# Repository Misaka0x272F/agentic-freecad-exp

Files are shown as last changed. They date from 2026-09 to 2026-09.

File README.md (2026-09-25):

# agentic-freecad-exp

Hands-on practice at **building real CAD with an agent driving FreeCAD** — and a
place to write down what that actually takes.

Not a reducer repository. Reducers happen to be the first project in it, because
they are unforgiving: a gear reducer has lots of parts, exact geometric
relationships, and mistakes that look fine in a render. That makes them a good
proving ground for the workflow.

The repository has two layers:

```
docs/practices/     knowledge that transfers to any agentic FreeCAD work
projects/           concrete builds, each self-contained and reproducible
```

---

## Practice notes

Design-agnostic, written from mistakes that got through. Read these before
building anything with an agent and FreeCAD.

| | |
|---|---|
| [Driving FreeCAD on another machine over MCP](docs/practices/01-remote-mcp-workflow.md) | architecture, setup, the IP-allowlist trap, where headless execution really runs, and why the remote environment must be re-probed every session |
| [FreeCAD API traps](docs/practices/02-freecad-api-traps.md) | 14 behaviours that fail **silently** — `Part::Feature.Shape` already carrying its placement, `Placement` rotating about the origin, booleans that return invalid solids, `distToShape` that cannot prove non-overlap, and the rest |
| [Verification methodology](docs/practices/03-verification-methodology.md) | how to prove generated geometry is correct rather than merely plausible: intersection volume, bounding-box pre-filtering, closed-form cross-checks, negative controls, orphan detection |
| [CAD assembly practice](docs/practices/04-cad-assembly-practice.md) | boolean ordering for castings, flange overhang and relief, bolt-head clearances, coplanar-face slivers, assembly-path constraints |

The short version, if you read nothing else:

1. **`Part::Feature.Shape` already has the Placement applied**, and assigning
   `.Shape` then `.Placement` bakes the rotation in and resets the Placement to
   identity. A local-frame feature cut through `obj.Shape` lands in the wrong
   place — silently, with `isValid()` still `True`.
2. **`distToShape == 0` cannot prove non-overlap.** Use intersection volume.
3. **Bounding boxes of boolean results are ~0.1 mm off** — enough to make an exact
   160.000 mm centre distance measure as 159.888 mm.
4. **`App.Placement` translates after rotating, about the origin.** To rotate about
   an arbitrary axis, `t = axis − R·axis`.
5. **Assert that features exist, and prove your checks can fail.** A verification
   step that has never failed is an untested verification step.

## Projects

| project | what it is | status |
|---|---|---|
| [reducers](projects/reducers/) | three cylindrical gear reducers (i = 3, 12, 8), script-generated, with an independent audit | two models committed and verified; the third is documented |

Each project is self-contained: its own `src/`, `models/`, `images/` and `docs/`.
Nothing in `projects/` is needed to understand `docs/practices/`, and vice versa.

<p align="center">
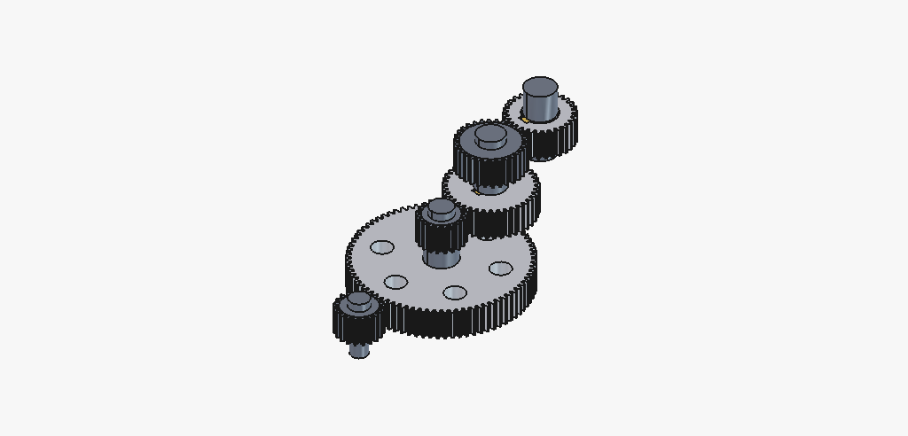
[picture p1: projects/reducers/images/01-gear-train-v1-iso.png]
three-stage gear train
  
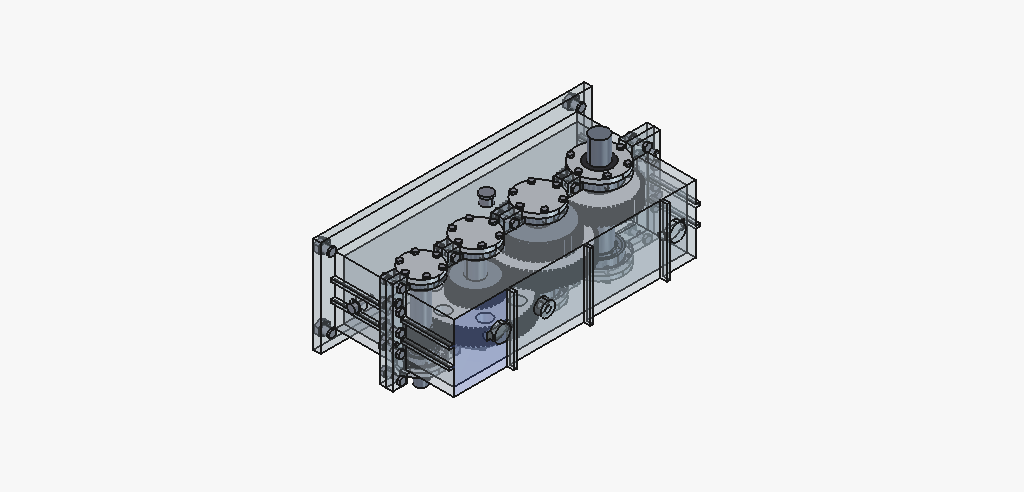
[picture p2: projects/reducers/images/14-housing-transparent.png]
assembly with translucent housing
  
</p>

```bash
git clone https://github.com/Misaka0x272F/agentic-freecad-exp
cd agentic-freecad-exp/projects/reducers

freecadcmd -P src -c "import build_two_stage as m; m.main()"   # build
freecadcmd -P src -c "import verify; verify.main('two')"       # audit
```

## Adding a project

`projects/reducers/` is the template. The conventions that make it work:

* **models are script-generated**, never hand-modelled — the script is the source
  of truth and the `.FCStd` is a build artifact;
* a project carries its own **design-conventions block** at the top of its shared
  library (`projects/reducers/src/common.py`); other sessions read that before
  contributing, rather than working from memory of a previous round;
* **build and verify are separate programs**, and the verifier re-opens the saved
  file rather than trusting the builder;
* anything learned that is *not* specific to the project goes into
  `docs/practices/`, not into the project's docs.

## Requirements

* FreeCAD with Python (`freecadcmd` on `PATH`) — developed against 1.0.0 and
  1.1.0
* the built-in `PartDesign.fcgear` module, shipped with FreeCAD; the FCGear addon
  is **not** needed
* `xvfb-run` only for offscreen rendering, and a lot of patience: software
  rendering of these models exceeded ten minutes per frame, which is why the
  committed images were captured from a native GUI instead

## Honesty notes

* These are **geometry** exercises. Nothing is stress-analysed; load capacity is
  not asserted anywhere.
* The practice notes describe one project's experience, not universal truths.
  Where two sessions observed *contradictory* behaviour from the same tool, the
  contradiction is recorded rather than resolved — see
  [the environment table](docs/practices/01-remote-mcp-workflow.md#probe-the-remote-environment-every-session--it-is-not-stable).
* `projects/reducers/models/original-build/` holds a first generation with
  defective hub keyways, kept as evidence rather than as reference geometry.

## License

MIT — see [LICENSE](LICENSE).

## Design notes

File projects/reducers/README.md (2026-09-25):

# Reducers

Three cylindrical gear reducers, built entirely by script and audited
part-by-part. This is the first project in the repository and the source of most
of the lessons now collected under [`docs/practices/`](../../docs/practices/).

| design | ratio | shafts | parts | material | model |
|---|---|---|---|---|---|
| [single-stage](docs/01-single-stage.md) | 3.000 | 2 | 14 | 7.74 L | `models/reducer_single_stage.FCStd` |
| [two-stage, expanded](docs/02-two-stage.md) | 12.000 | 3 | 21 | 16.34 L | `models/reducer_two_stage.FCStd` |
| [three-stage, expanded](docs/03-three-stage.md) | 8.000 | 4 | 41 | ≈ 22.6 L | *(not committed — see below)* |

Each design is a complete transmission plus its enclosure: involute gears with
genuine tooth profiles and root fillets, stepped shafts with GB/T 1096 keyways,
deep-groove ball bearings with balls, flanged end caps (through and blind), and a
split cast housing with bearing bosses, flanges, ribs and bolt holes.

| | single-stage | two-stage | three-stage |
|---|---|---|---|
| module | m = 4 | m₁ = 3, m₂ = 4 | m = 3 |
| teeth | 20 / 60 | 20 / 80 and 20 / 60 | 20 / 80, 38 / 76, 56 / 56 |
| centre distances | 160 | 150 and 160 | 150, 171, 168 |
| bearings | 6206 ×2, 6209 ×2 | 6206 ×2, 6209 ×2, 6214 ×2 | 6207 / 6208 / 6209 / 6211 |
| end caps | 2 through + 2 blind | 2 through + 4 blind | 2 through + 6 blind |

The two-stage and three-stage designs are **expanded** (展开式) layouts: the
intermediate shafts carry the wheel of one stage and the pinion of the next, so
the meshes sit at different axial stations. See
[docs/02](docs/02-two-stage.md) for why that shapes everything.

## Layout

```
src/
  common.py              reusable geometry + this project's design conventions
                         (read the docstring at the top first)
  housing.py             parameterised split-cast housing builder
  build_single_stage.py  design 1
  build_two_stage.py     design 2
  verify.py              independent audit; exits non-zero on failure
  render.py              offscreen PNG rendering (GUI-only; slow under Xvfb)
render.sh                wrapper that runs render.py
models/                  the two verified models, plus original-build/ holding the
                         first generation, whose hub keyways are defective
images/                  process renders: gear train, housing iterations,
                         bearings and end caps, assembly
docs/                    per-design records, the audit write-up, design notes
```

## Running it

```bash
cd projects/reducers

freecadcmd -P src -c "import build_single_stage as m; m.main()"
freecadcmd -P src -c "import build_two_stage as m; m.main()"

freecadcmd -P src -c "import verify; verify.main('single')"   # exits non-zero on failure
freecadcmd -P src -c "import verify; verify.main('two')"
```

`freecadcmd` treats a positional filename as a document to open, so the modules
have to be imported — see
[API traps §13](../../docs/practices/02-freecad-api-traps.md#13-freecadcmd-scriptpy-does-not-run-the-script).

## Verification results

Every committed model is audited by a **separate** program that re-opens the saved
file and re-derives geometry from scratch — it does not trust the builder.

| check | single-stage | two-stage |
|---|---|---|
| solids valid | 14 / 14 | 21 / 21 |
| centre distance, measured from cylindrical faces | 160.000000 mm | 150.000000 / 160.000000 mm |
| pairs with non-zero intersection volume | **0** of 91 | **0** of 210 |
| gear meshes touching without overlap | ✓ | ✓ both stages |
| keyway cut volume vs closed-form solution | 4 / 4 exact | 6 / 6 exact |
| tooth counts recovered by clustering tip vertices | 20 / 60 ✓ | 20 / 80 / 20 / 60 ✓ |

Three-stage build, as recorded by its session: 41 parts all valid, 820 pairs
pre-filtered to 201 candidates, **all zero**; connectivity analysis returns a
single component (no orphan parts); ratio 4.000 × 2.000 × 1.000 = 8.000.

Full output: [docs/04-verification.md](docs/04-verification.md).

## Design conventions

Full text at the top of `src/common.py`:

* millimetres and degrees;
* **shaft axes along +X, all axes in the plane z = 0** — the housing is split
  along that plane into `Housing_Base` (z < 0) and `Housing_Cover` (z > 0);
* gears are built in a local frame (**axis +Z, tooth centre on local +X**) and
  placed by `gear_placement()`;
* flat keys per GB/T 1096, selected by `key_for(shaft_diameter)`.

Anything built for this project must follow them. In particular, a model built
with a different convention cannot simply be dropped in — see
[assembly practice §9](../../docs/practices/04-cad-assembly-practice.md#9-coordinate-system-drift-between-sessions-is-a-real-risk).

## Why the three-stage model is not committed

Its 41 parts live only on the CAD host, and committing the binary would
contradict the point of the repository, which is that **models are produced by
scripts**. [docs/03-three-stage.md](docs/03-three-stage.md) records the design,
the process, the verification, and the fact that it was built in a *different*
coordinate convention (shafts along +Z, split at X = 0) — so it needs rotating
into this project's frame before it can be merged, not copying. That document is
in Chinese; the rest of this project's docs are in English.

## Honesty notes

* This is a **geometry** exercise. Nothing is stress-analysed: modules, tooth
  counts and widths were chosen for sensible proportions, not from a strength
  calculation. Load capacity is not asserted.
* Fasteners are modelled as **holes** in designs 1 and 2; the three-stage build
  modelled them as solids and hit the interference problems recorded in
  [assembly practice](../../docs/practices/04-cad-assembly-practice.md) as a
  result.
* Bearings are simplified: rings and balls, no cage, no fillets, catalogue sizes.
* `models/original-build/` holds the first-generation files, which have defective
  hub keyways and spurious rim slots — they are kept as evidence, not as
  reference geometry. The committed models are rebuilt with the fix and fully
  audited.

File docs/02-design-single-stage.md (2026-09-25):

# Design 1 — single-stage cylindrical gear reducer

`src/build_single_stage.py`

## Specification

| | |
|---|---|
| module | m = 4 mm |
| pressure angle | α = 20° |
| teeth | z₁ = 20 (pinion) / z₂ = 60 (wheel) |
| ratio | i = 3.000 |
| pitch diameters | d₁ = 80 mm, d₂ = 240 mm |
| tip / root diameters | 88 / 70 mm and 248 / 230 mm |
| centre distance | a = 160 mm |
| face widths | 50 mm (pinion), 45 mm (wheel) |
| bearings | 6206 (30×62×16) ×2, 6209 (45×85×19) ×2 |

Shaft axes lie in the plane `z = 0`, 160 mm apart along Y. Stage layout is
deliberately the simplest possible: one gear pair, no axial offset.

```
        y
        ▲
  160 ──┼──────────────●  shaft II (output, extends right)
        │             ╱ ╲
        │            │   │  wheel z=60
        │             ╲ ╱
        │              │
        │              ●   mesh, a = 160
        │             ╱ ╲
    0 ──┼────────────●   │  pinion z=20
        │             ╲ ╱
        └──────────────▶ x
                        shaft I (input, extends left)
```

## Shafts

Both shafts are stepped, with the shoulder between the gear seat and the bearing
seat acting as the axial locating feature for both the gear hub and the bearing
inner ring.

| shaft | segments (Ø × x-range) | length | extension |
|---|---|---|---|
| I (input) | Ø25 `[-120,-78]`, Ø30 `[-78,-40]`, Ø36 `[-40,40]`, Ø30 `[40,55]` | 175 | left |
| II (output) | Ø45 `[-55,-37]`, Ø55 `[-37,37]`, Ø45 `[37,56]`, Ø40 `[56,115]` | 170 | right |

The input shaft carries the pinion on its Ø36 seat; the output shaft carries the
wheel on its Ø55 seat. The extension ends are Ø25 and Ø40, ready for a coupling.

## Keyways

Four keyways, GB/T 1096 flat keys, chosen from the shaft diameter by
`key_for()`:

| location | shaft Ø | key b×h | groove t₁ | length | cut volume vs analytic |
|---|---|---|---|---|---|
| input, gear seat | Ø36 | 10×8 | 5.0 | 50 mm | 2382.9 / 2382.9 mm³ |
| input, coupling | Ø25 | 8×7 | 4.0 | 36 mm | 1089.6 / 1089.6 mm³ |
| output, gear seat | Ø55 | 16×10 | 6.0 | 45 mm | 4037.1 / 4037.1 mm³ |
| output, coupling | Ø40 | 12×8 | 5.0 | 37 mm | 2084.9 / 2084.9 mm³ |

Both coupling keyways are **open at the shaft end** so a coupling hub can slide
on. All keyways on one shaft share an angular direction, as they would if milled
in a single setup; that direction is inherited from the gear's mesh phase.

Matching hub grooves (`t₂`) are cut into the gear bores in the gears' own local
frames — see `make_gear_solid(..., key=...)`.

## Bearings and end caps

Bearings sit flush with the inner end of the housing bore, so the outer face of
each bearing lands exactly on the plane the cap spigot reaches. That is what
makes the cap clamp the bearing outer ring.

| | input | output |
|---|---|---|
| bearing | 6206, 30×62×16 | 6209, 45×85×19 |
| bore in housing | Ø62 | Ø85 |
| cap bolt circle D₀ | 82 | 105 |
| cap flange D₂ | 102 | 125 |

Cap sizes follow the standard flanged pattern with M8 screws:

```
D0 = D + 2.5·d3 = D + 20      bolt circle
D2 = D0 + 2.5·d3 = D + 40     flange outside diameter
e  = 1.2·d3 = 9.6 → 10 mm     flange thickness
e1 = 0.8·e = 8 mm             spigot length
```

Two through caps (input-left, output-right — where the shafts leave the housing),
two blind caps.

## Housing

Split along the plane through both shaft axes (`z = 0`) into `Housing_Base`
(z < 0) and `Housing_Cover` (z > 0).

| dimension | value |
|---|---|
| cavity lobes | (y=0, r=56), (y=160, r=136) — gear tip radius + 12 mm |
| wall thickness | 8 mm |
| cavity axial half-length | 37 mm |
| end wall / boss face | ±47 / ±64 mm |
| oil-sump floor | z = −130 mm (6.1 mm below the wheel's lowest tooth) |
| casting bottom | z = −140 mm |
| split flange | 12 mm per half, 24 mm radial overhang |
| bore length | 27 mm (bearing + 8 mm spigot) |

The lower half is a rectangular box rather than a continuing circle: real bases
are boxy, and it gives a genuinely flat bottom. The cover is the two-lobe dome.
The split flange is a rim around the outline plus an "ear" around each bearing
boss, so the bearing-adjacent bolts have material to sit in.

Bolting: 4 × M8 per end cap, 12 split-flange bolts, 4 foundation bolts.

## Result

14 parts, 7744.2 cm³ of material (≈ 56 kg as cast iron), all solids valid, every
pairwise intersection volume zero, centre distance exactly 160.000000 mm, and
both meshes touching without overlap.

See [verification](05-verification.md) for the full audit output.

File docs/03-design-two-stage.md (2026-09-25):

# Design 2 — expanded two-stage cylindrical gear reducer

`src/build_two_stage.py`

## Specification

| | stage 1 (high speed) | stage 2 (low speed) |
|---|---|---|
| module | m₁ = 3 mm | m₂ = 4 mm |
| teeth | z₁ = 20 / z₂ = 80 | z₃ = 20 / z₄ = 60 |
| ratio | i₁ = 4.000 | i₂ = 3.000 |
| pitch diameters | 60 / 240 mm | 80 / 240 mm |
| tip diameters | 66 / 246 mm | 88 / 248 mm |
| centre distance | a₁ = 150 mm | a₂ = 160 mm |
| face widths | 55 / 50 mm | 65 / 60 mm |

**Total ratio i = i₁ · i₂ = 12.000.**

| shaft | y | role | extension |
|---|---|---|---|
| I | 0 | high speed | extends left |
| II | 150 | intermediate | fully enclosed |
| III | 310 | low speed | extends right |

| | shaft I | shaft II | shaft III |
|---|---|---|---|
| gear carried | stage-1 pinion | stage-1 wheel **and** stage-2 pinion | stage-2 wheel |
| gear bore | Ø36 | Ø50 / Ø50 | Ø80 |
| bearing | 6206 (30×62×16) | 6209 (45×85×19) | 6214 (70×125×24) |
| housing bore | Ø62 | Ø85 | Ø125 |
| cap bolt circle / flange | 82 / 102 | 105 / 125 | 145 / 165 |

## Why the two meshes sit at different axial stations

This is the defining feature of the **expanded (展开式)** layout: the intermediate
shaft carries the stage-1 wheel *and* the stage-2 pinion. Both gears are on the
same axis, so the two meshes cannot share an axial band.

```
                    stage 2 mesh (x = +45)          stage 1 mesh (x = -45)
                                                       
  y=310  ●━━━━━━━━━━━━━━━━━━━━━━━━━━━━●  G4 wheel z=60 (green)
                                        ╲
                                         ╲  a2 = 160
                                        ╱
  y=150  ●━━━━● G3 pinion z=20 (red)   ●━━━━● G2 wheel z=80 (yellow)
                ╲                     ╱
                 ╲  a1 = 150         ╱
                ╱                   
  y=0    ●━━━━● G1 pinion z=20 (orange)
         └──────────────────────────────▶ x
        x = -45                x = +45
```

Consequences that shaped the geometry:

* the gear bands must not overlap axially — stage-1 gears occupy
  `x ∈ [-72.5, -17.5]`, stage-2 gears `x ∈ [12.5, 77.5]`;
* the housing cavity is correspondingly long: `x ∈ [−82, +82]`;
* the intermediate shaft carries two gears with **different** mesh phases, so its
  two keyways point in different directions.

Gear 2 (z₂ = 80) and gear 3 (z₃ = 20) are radially nested — the big wheel and the
small pinion are concentric on shaft II — which is only possible because they are
axially separated.

## Axial layout

| | value |
|---|---|
| cavity half-length | 82 mm |
| end wall / boss face | ±92 / ±114 mm |
| bearing outer face | ±106 mm (boss face − 8 mm spigot) |
| cap flange | ±[114, 124] mm |

Shaft diameter steps are placed **outside** the cap spans `|x| ∈ [106, 124]`, so
that a through cap's central bore — sized on the smaller diameter — cannot
collide with a larger section. This is a direct consequence of a bug found and
fixed during the build; see
[lessons-learned D4](06-lessons-learned.md#d4-clearances-the-housing-must-respect).

## Shafts

| shaft | segments (Ø × x-range) | length |
|---|---|---|
| I | Ø25 `[-165,-126]`, Ø30 `[-126,-85]`, Ø36 `[-85,-5]`, Ø30 `[-5,105]` | 270 |
| II | Ø45 `[-105,-72]`, Ø50 `[-72,-18]`, Ø45 `[-18,10.5]`, Ø50 `[10.5,79.5]`, Ø45 `[79.5,105]` | 210 |
| III | Ø70 `[-105,9]`, Ø80 `[9,81]`, Ø70 `[81,126]`, Ø65 `[126,165]` | 270 |

The intermediate shaft has **no** extension: both of its ends are enclosed, so it
gets two blind caps. The Ø45 spacer between its two Ø50 gear seats provides the
shoulders that locate the wheel and the pinion.

## Keyways

Six keyways — two per shaft (gear seat + coupling where the shaft extends).

| location | shaft Ø | key b×h | t₁ | length | cut / analytic |
|---|---|---|---|---|---|
| I gear seat | Ø36 | 10×8 | 5.0 | 55 mm | 2621.2 / 2621.2 mm³ |
| I coupling | Ø25 | 8×7 | 4.0 | 36 mm | 1059.3 / 1059.3 mm³ |
| II wheel seat | Ø50 | 14×9 | 5.5 | 50 mm | 3618.6 / 3618.6 mm³ |
| II pinion seat | Ø50 | 14×9 | 5.5 | 65 mm | 4704.1 / 4704.1 mm³ |
| III wheel seat | Ø80 | 22×14 | 9.0 | 60 mm | 11206.7 / 11206.7 mm³ |
| III coupling | Ø65 | 18×11 | 7.0 | 37 mm | 4263.6 / 4263.6 mm³ |

Note that shafts I and III each extend from one end, so the coupling keyway is
open at the free end while the gear-seat keyway is closed — the analytic volume
is computed on the *effective* length, i.e. the part of the cutter that is
actually inside the material.

## Housing

| dimension | value |
|---|---|
| cavity lobes | (y=0, r=45), (y=150, r=135), (y=310, r=136) |
| wall thickness | 8 mm |
| cavity half-length | 82 mm |
| oil-sump floor | z = −130 mm (6.0 mm below the stage-2 wheel's lowest tooth) |
| casting bottom | z = −140 mm |
| split flange | 12 mm per half, 24 mm overhang |
| base plate | 200 × 531 × 19 mm, 4 × M18 foundation bolts |

Bolting: 4 × M8 per end cap (6 caps), split-flange bolts at both Y extremes and
in pairs beside each bearing boss, 4 foundation bolts.

## Result

21 parts, 16336.3 cm³ (≈ 118 kg as cast iron), all solids valid, all 210 pairwise
intersection volumes zero, both centre distances exact to 10⁻⁶ mm, both meshes
touching without overlap.

See [verification](05-verification.md) for the full audit output.

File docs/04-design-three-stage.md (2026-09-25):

# 三级展开式圆柱齿轮减速器 i = 4 / 2 / 1

**状态**：模型已完成并通过全部校验，但**尚未入库**——本体只在远程 FreeCAD 上
（`<cad-host>:/Reducer_Full_i4_2_1.FCStd`），本仓库的 `models/`
和 `src/` 里还没有对应产物。原因与建议见第 5、6 节。

**坐标约定**：本模型用**轴沿 +Z、箱体沿 X=0 剖分**，与仓库约定（轴沿 +X、
沿 z=0 剖分）不同。这是本次最大的遗留问题，见 5.1。

---

## 1. 任务

分四轮：

1. 新建 FreeCAD 项目，绘制传动比 4/2/1 的直齿圆柱齿轮减速器 → 需求确认为
   **三级减速，各级 i₁=4、i₂=2、i₃=1，总 8:1**；范围为**仅传动系统**
2. 追加**箱体、轴承、端盖** → 确认为**剖分式箱体**、**深沟球轴承**、
   **含标准附件**，并**允许重配齿数**（传动比严格不变）
3. 箱体与箱盖改为**透明**
4. 清理**多余/游离结构**

---

## 2. 最终设计参数

### 2.1 齿轮

m = 3，α = 20°，hₐ\* = 1.0，c\* = 0.25，齿宽 b = 40。

| 齿轮 | z | 分度圆 | 齿顶圆 | 齿根圆 | 所在轴 | 轴向区段 (Z) |
|---|---|---|---|---|---|---|
| z1 | 20 | Ø60 | Ø66 | Ø52.5 | I | 0 – 40 |
| z2 | 80 | Ø240 | Ø246 | Ø232.5 | II | 0 – 40 |
| z3 | 38 | Ø114 | Ø120 | Ø106.5 | II | 45 – 85 |
| z4 | 76 | Ø228 | Ø234 | Ø220.5 | III | 45 – 85 |
| z5 | 56 | Ø168 | Ø174 | Ø160.5 | III | 90 – 130 |
| z6 | 56 | Ø168 | Ø174 | Ø160.5 | IV | 90 – 130 |

齿数比：80/20 = **4.000**，76/38 = **2.000**，56/56 = **1.000**，总 **8.000**。

轴心（Y）：I = 0，II = 150，III = 321，IV = 489。
中心距：a₁₂ = 150，a₂₃ = 171，a₃₄ = 168。

**齿数是被重配过的**（第一轮是 20/80/20/40/30/30）。原因：展开式布局要求第一级
大齿轮的齿顶圆让开下一根轴，即

```
da₂/2 + d_III(轴颈)/2 + Δ  <  a₂
```

第一轮 20/80/20/40 时 da₂/2 = 123 而 a₂ = 90，齿顶**扫过 III 轴中心线 33 mm**，
三级齿轮被迫沿轴向错开 180 mm，III 轴就无法伸到第一级的轴向区段去装轴承——
箱体做不成标准两壁结构。

重配后：`123 + 22.5 = 145.5 < 171`（余量 25.5），
`117 + 27.5 = 144.5 < 168`（余量 23.5），三级齿轮得以收进同一轴向区段
（三个 40 mm 齿宽带，带间 5 mm）。

### 2.2 轮齿相位

`PartDesign.fcgear` 把齿中心放在局部 0°，齿槽中心在 `180/z`。对每一对啮合
（小轮在低 Y 侧）：

```
φ_小轮 = 90°                        （齿中心指向 +Y）
φ_大轮 = 270° − 180°/z_大轮          （齿槽中心指回 −Y）
```

实际取值：z1 90°，z2 267.750°，z3 90°，z4 267.6316°，z5 90°，z6 266.7857°。

### 2.3 轴系

四根轴都是阶梯轴，带轴承轴颈、定位轴肩、装拆台阶（轴承从轴端滑入并靠轴肩
定位）。z1 / z3 / z5 为**整体齿轮轴**。

| 轴 | 轴承 | 轴颈 | 齿轮轴颈 | 轴伸 |
|---|---|---|---|---|
| I（输入） | 6207 | Ø35 | 齿体 Ø52.4 | Ø30，Z −100…−40 |
| II | 6208 | Ø40 | z2 座 Ø45 / 齿体 Ø106.4 | 无 |
| III | 6209 | Ø45 | z4 座 Ø50 / 齿体 Ø160.4 | 无 |
| IV（输出） | 6211 | Ø55 | z6 座 Ø60 | Ø48，Z 174…250 |

平键按 GB/T 1096，键长 36：

| 齿轮 | 轴径 | 键 | t₁ | t₂ |
|---|---|---|---|---|
| z2 | Ø45 | 14×9 | 5.5 | 3.8 |
| z4 | Ø50 | 16×10 | 6.0 | 4.3 |
| z6 | Ø60 | 18×11 | 7.0 | 4.4 |

### 2.4 箱体

剖分面取 **X = 0**（四根轴心恰好都在该面上），箱座 X<0、箱盖 X>0。

| 项 | 值 |
|---|---|
| 壁厚 | 12 |
| 内腔 | X (−163, 138)，Y (−48, 591)，Z (−15, 145) |
| 外形 | X (−175, 150)，Y (−60, 603)，Z (−27, 157) |
| 剖分凸缘 | 厚 18，四周外伸 35 |
| 轴承座凸台 | Ø100 / 110 / 115 / 130，外伸 13 / 14 / 15 / 17 |
| 轴承孔深 | 轴承宽 + 8（留 6 mm 止口） |
| 地脚凸缘 | X (−195, −175)，4×Ø24 |
| 油池 | 液面 X = −103，最大齿轮 z2 浸油 20 mm（≈1/6 半径） |
| 加强肋 | 箱盖顶面 3 道（Y = 90 / 300 / 510）；两端壁各 2 道（Z = 45 / 95） |

### 2.5 轴承与端盖

8 套深沟球轴承，每套含内圈、外圈、9 颗滚球，做成 `Part.makeCompound` 复合体。
8 个端盖：**2 个透盖**（输入轴 Ø30 油封 30×47×7、输出轴 Ø48 油封 48×72×8）
+ **6 个闷盖**；每个端盖 6×M8，止口 6 mm。
端盖螺栓在凸台里配 Ø6.8×16 螺纹底孔。

### 2.6 标准附件

剖分面螺栓 M12×16（头 + 螺母）· 定位圆锥销 Ø10×2 · 起盖螺钉 M10×2 ·
放油螺塞 M20 · 油标尺 · 通气器 · 地脚螺栓 M20×4 · 吊环凸台 ×2

---

## 3. 过程

### 3.1 第一轮：仅传动系统

先探测远程 API：`Gui` 模块不可用、`App.Vector` 不存在，但
`PartDesign.fcgear` 可通过 `fcgear.fcgear.FCWireBuilder` 调用。

动手前先用**布尔干涉量**验证啮合相位公式：正确相位下 `common()` 体积 = 0，
把从动轮再转过半个齿距则得到 ~1900 mm³ 干涉——先确认这个判据有区分度，再拿它
当尺子用（见 lessons-learned 4.4）。

然后建 6 齿轮 + 4 轴 + 3 键，45 对零件干涉全为 0。

### 3.2 第二轮：完整减速器

**先发现齿数不可用**（见 2.1），重配齿数 → 重建传动系 → 建箱座/箱盖 →
建轴承/端盖 → 补附件。

这一轮踩的坑最多，按被发现顺序：

| # | 现象 | 根因 | 对策 |
|---|---|---|---|
| 1 | 箱体与传动系**全部**干涉 | 剖分凸缘是实体板，我**先切内腔后并凸缘**，凸缘把内腔填实了 | 改为先并完所有凸缘/凸台，**最后**切内腔 |
| 2 | 轴伸与箱体干涉 | 剖分凸缘沿 ±Z 外伸 35 挡住了轴伸 | 在每个轴承座处挖避让孔（半径 = 凸台半径 + 8，Z 只到凸台端面） |
| 3 | 凸缘螺栓与箱座干涉 26905 mm³ | 凸缘在 Z 向不外伸，螺母埋在箱座实体里 | 给 Z 向外伸（配合 #2 的避让孔） |
| 4 | 轴承内圈与轴干涉 | 内圈内孔半径写成了 `d/2 − 1`（比轴颈小 1 mm） | 改为 `d/2 + 0.05`（0.1 mm 间隙） |
| 5 | 闷盖与端盖螺栓干涉 3619 mm³ | `end_cap()` 里的螺栓孔布尔**静默未生效** | 单独再切一次螺栓孔；螺栓分 Ø8 穿盖段 + Ø6.6 入螺孔段 |
| 6 | 凸缘螺栓头与端壁加强肋干涉 | 六角头外接圆 0.577·af 与肋相碰 | 肋从 Z=30/110 挪到 Z=45/95 |
| 7 | 起盖螺钉与凸缘螺栓干涉 | 两者间距 14.8 < 所需 19.6 | 挪到 Y 向凸缘中部（Z=45 / 145） |
| 8 | 螺栓头/螺母端面与凸缘面残留 111 mm³ 干涉 | 精确共面产生数值薄片 | 端面内缩 0.2 mm |

期间还出现过一次**误判为卡死**：最后那条全量校验（41 件 820 对）跑了 2 分钟
多，用户以为 FreeCAD 挂了。`get_rpc_status` 报 `state: busy` 才确认是在跑。
之后改成包围盒预筛，820 → 201 对，秒级完成（见 lessons-learned 4.3、5.3）。

### 3.3 第三轮：透明

箱座/箱盖 `ViewObject.Transparency = 75`，便于看内部传动系。

### 3.4 第四轮：清理多余结构

用户指出通气器「游离在主体外」。用**连通性分析**（包围盒重叠 + 并查集）定量
确认：`Breather` 自成连通分量，**离最近零件 50.3 mm**。

根因是**建模辅助函数的轴向 bug**：我用沿 +Z 构建的 `cyl()` 去造通气器（它应沿
+X），而 `.translated()` 只平移、不换轴。同一轮还查出放油螺塞的六角头也拐错了
方向——`hex_prism(..., axis='Y')` 只实现了 `'X'` 分支，非法取值被**静默忽略**。

两处都改为显式指定轴线后重建，并顺手把螺塞头部与凸台端面的 3 mm 缝隙贴平
（基准面取错：把箱壁外表面 Y=603 当成了凸台端面 Y=619）。

---

## 4. 校验

| 项目 | 结果 |
|---|---|
| 零件数 | 41，全部 `isValid() == True` |
| 两两干涉 | 包围盒预筛 820 → 201 对，**干涉全为 0** |
| 连通分量 | **1**（无游离件） |
| 传动比 | 4.000 × 2.000 × 1.000 = **8.000** |
| 展开式让空 | 145.5 < 171；144.5 < 168 |
| 啮合相位 | 正确相位干涉 0；错开半齿距 ~1900 mm³（判据有区分度） |
| 整机外形 | Y 743 × Z 365；X ≈ 403（−207.5 … 196，X 上限来自通气器顶盖） |

**存档凭据**（远程）
- `Reducer_Full_i4_2_1.FCStd` — 完整减速器，41 件，811.6 KB
- `Reducer_i4_2_1.FCStd` — 仅传动系统的第一轮版本

> 最终体积/质量的精确复测未能完成：写本文时远程 FreeCAD 的 GUI 调度被占
> （`get_rpc_status` 报 healthy，但 `execute_code` 排队 90 s 都进不去 —— 典型的
> 远程端开着模态对话框）。按 41 件的材料体积约 22.6 L 估，钢制约 177 kg。

---

## 5. 与仓库约定的偏差

### 5.1 坐标系（重要）

| | 本仓库约定 | 本次模型 |
|---|---|---|
| 轴方向 | **+X** | **+Z** |
| 轴心所在平面 | z = 0 | y = 0 |
| 剖分面 | z = 0 | **X = 0** |
| 齿轮局部系 | 轴 +Z、齿中心局部 +X | 同（一致） |
| 箱座/箱盖 | `Housing_Base` (z<0) / `Housing_Cover` (z>0) | `HousingBase` (X<0) / `HousingCover` (X>0) |

两套系的 `Placement`、相位公式、端盖/轴承的轴向定义、视图方向全都不同。三级模型
若要并入本仓库，需要整体旋转到 +X / z=0 系，**不能**直接混用。

### 5.2 未复用仓库的工具

本次没有 import `src/common.py`，而是在远程手搓脚本（常量写成一个
`reducer_params.py` 模块 import 以避免漂移）。代价是重复实现且偏离约定；
仓库里已有的 `mesh_phases()`、`key_for()`、`make_bearing()`、`make_end_cap()`、
`cap_dimensions()` 本都可以直接用。

### 5.3 命名

仓库用 `Housing_Base` / `Housing_Cover` / `Gear_*` / `Shaft_*`（带下划线前缀），
本次用了 `HousingBase` / `HousingCover`。

---

## 6. 后续建议（按价值排序）

1. **按仓库约定重写 `src/build_three_stage.py`**，用 `common.py` 的
   `mesh_phases` / `make_shaft` / `make_bearing` / `make_end_cap` / `key_for`，
   转到 +X / z=0 系，输出 `models/reducer_three_stage.FCStd`。
   这比把远程的二进制拷进来有价值得多——仓库的约定就是**模型由脚本生成**。
   `src/housing.py` 的 `build_housing()` 目前按「每根轴一个圆瓣」的轮廓建箱体，
   三级（4 根轴、轴心 0/150/321/489 共线）需要确认它能直接吃下这个 spec。
2. **把三级加入 `src/verify.py` 的 `MODELS`**，复用它的独立复算：齿数/齿顶半径/
   齿宽、轮毂键槽角度、轴同轴度、中心距、两两干涉。
3. **补 `src/render.py`**（`common.py` 顶部已声明颜色/截图应集中在此）。
4. 补 `README.md`，并 `git init` 纳入版本管理。

---

## 7. 图集

`images/` 按过程顺序：

| 文件 | 内容 |
|---|---|
| `01-gear-train-v1-iso.png` | 第一轮传动系（齿数 20/80/20/40/30/30），等轴测 |
| `02-gear-train-v1-top.png` | 第一轮俯视：四轴共线布局 |
| `03-gear-train-v1-front.png` | 第一轮正视：三级齿轮轴向错开 180 mm |
| `04-gear-train-v2-iso.png` | 重配齿数后的传动系 |
| `05-housing-base.png` | 箱座（内含传动系） |
| `06-housing-cover.png` | 箱盖 |
| `07-housing-cavity-fixed.png` | 修正布尔顺序（先并后挖）之后的箱体 |
| `08-housing-bore-audit-top.png` | 轴承座孔与凸台俯视核对 |
| `09-bearings-and-end-caps.png` | 轴承与端盖装好 |
| `10-accessories.png` | 补上标准附件 |
| `11-flange-bolts-rebuilt.png` | 凸缘螺栓按新方位重建 |
| `12-housing-final-top.png` | 箱体最终俯视：凸缘四周外伸 + 16 颗螺栓 |
| `13-assembly-coloured.png` | 全装配上色 |
| `14-housing-transparent.png` | 箱体透明，可见内部传动系 |
| `15-assembly-left.png` | 左视：轴承座、端盖、端壁肋 |

---

## 8. 经验教训

完整的坑清单在 [`docs/06-lessons-learned.md`](06-lessons-learned.md)，其中带 `[3rd]`
标记的条目来自本次会话。最值得记住的三条：

1. **先并后挖**：箱体类零件的凸缘是实体板，必须并完所有凸台再切内腔。
2. **大批量干涉校验先做包围盒预筛**：820 对要 2 分钟且看起来像死机，
   预筛后秒级完成、结论不变。
3. **辅助函数要把「轴」写进名字或做参数校验**：沿 Z 的 `cyl()` 被
   `.translated()` 调用时不会报错，只会静默产出错轴零件。

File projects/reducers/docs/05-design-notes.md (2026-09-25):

# Design notes

Notes specific to cylindrical gear reducers, as opposed to the general FreeCAD
practice collected under [`docs/practices/`](../../../docs/practices/).

---

## 1. Integral gear shaft (齿轮轴) criterion

A pinion is made integral with its shaft when its root circle is close to the
shaft diameter; the usual rule of thumb is `d_f / d_shaft < 1.5`.

| gear | d_f | shaft | ratio | verdict |
|---|---|---|---|---|
| stage-1 pinion (m=3, z=20) | 52.5 | Ø36 | 1.46 | marginal — integral is reasonable |
| stage-2 pinion (m=4, z=20) | 70 | Ø50 | 1.40 | marginal — integral is reasonable |
| stage-1 wheel (z=80) | 232.5 | Ø50 | 4.65 | separate gear |
| stage-2 wheel (z=60) | 230 | Ø80 | 2.88 | separate gear |

A 240 mm wheel on an output shaft is emphatically **not** a gear-shaft candidate:
an integral Ø230 blank on a Ø80 shaft wastes material, cannot be replaced when
worn, and gains nothing.

## 2. Expanded (展开式) layout

The intermediate shaft carries both the wheel of one stage and the pinion of the
next, so the two meshes must sit at **different axial stations**. Both gears of a
mesh share an axial band; the bands are offset. The shaft axes are collinear in
plan view.

Consequences that shape the whole design:

* gear bands must not overlap axially;
* the housing cavity becomes correspondingly long;
* an intermediate shaft carrying two gears has **two keyways pointing in
  different directions**, since each follows its own gear's mesh phase.

## 3. Meshing phase for a pair whose line of centres is along +Y

With the gear axis laid along +X and the gear spun by `ψ` about that axis, a
feature at local angle `θ` points at world direction `(0, sin(θ+ψ), −cos(θ+ψ))`.
For a standard (zero-backlash) mesh:

* pinion: tooth towards the wheel → `ψ_p = 90° − 0°`
* wheel: space towards the pinion → `ψ_w = 270° − 180°/z_w`

The wheel's `180°/z_w` term is the half-tooth-pitch offset between a tooth centre
and a space centre in the generator's convention. Measured result: the pair then
touches at exactly one point (`distToShape == 0.0000 mm`) with **zero**
intersection volume.

### Establishing the generator's convention

`PartDesign.fcgear` centres a **tooth on the local +X axis**, with a space at half
pitch. That was measured, not assumed, and the first measurement was wrong:

the tip of an involute tooth as generated here is effectively a **point** — the
plateau where `r == r_tip` is 0.048° wide, while the root plateau is 2.57° wide.
Scanning for "the angle that maximises the radius" therefore returns whichever
edge of the plateau the scan reaches first, and the phase came out ~1.8° off.

Two reliable methods:

* evaluate the radius at candidate angles directly
  (`r(0°) = 44.002`, `r(9°) = 35.000`, …);
* find the flank crossings of the pitch circle, where `r == m·z/2`.

Both gave the same answer.

## 4. Clearances

* cavity wall radius = gear tip radius + 10…15 mm (12 used here);
* the **oil-sump floor must clear the lowest tooth of the whole train** — see
  [assembly practice §8](../../../docs/practices/04-cad-assembly-practice.md);
* a bottom wall of ≥ 8–10 mm below the sump floor;
* the expanded layout's axial length is driven by the sum of the two gear bands
  plus the gap between them.

## 5. Layout choices made in these designs

* shafts axes all in the plane `z = 0`, so the housing splits along that plane;
* each shaft extends from **one** end only, which is what makes the through/blind
  cap split meaningful (an enclosed intermediate shaft gets two blind caps);
* gear hubs are keyed, not shrunk or splined, so every gear seat has a keyway and
  every hub has a matching groove at the same angular position.

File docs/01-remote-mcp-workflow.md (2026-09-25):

# The remote-MCP workflow

## Goal

Drive **FreeCAD running on a different machine** from an agent, over the
[Model Context Protocol](https://modelcontextprotocol.io), and produce real
engineering geometry rather than a toy demo.

```
┌─ agent machine ────────────────────────────┐   ┌─ CAD machine ────────────────┐
│                                            │   │                              │
│  CodeBuddy  ──stdio──▶  freecad-mcp        │   │   FreeCAD (GUI)              │
│  (LLM agent)            (MCP server,       │   │     └─ FreeCADMCP addon      │
│                          `uvx freecad-mcp  │──XML-RPC──▶  XML-RPC server     │
│                           --host HOST`)    │   │              :9875           │
│                                            │   │     (IP-allowlisted,         │
│                                            │   │      GUI-thread dispatch)    │
└────────────────────────────────────────────┘   └──────────────────────────────┘
```

Two components are involved and they are easy to confuse:

| component | runs on | role |
|---|---|---|
| `freecad-mcp` (Python package) | the **agent** machine | MCP server; translates MCP tool calls into XML-RPC |
| `FreeCADMCP` addon | the **CAD** machine, inside FreeCAD | XML-RPC server; executes code on FreeCAD's GUI thread |

## Setup

### 1. On the CAD machine

Copy `addon/FreeCADMCP` from the freecad-mcp repository into FreeCAD's addon
directory, restart FreeCAD, switch to the **MCP Addon** workbench, and in the
**FreeCAD MCP** toolbar:

1. tick **Remote Connections** (the server will bind `0.0.0.0` on next restart);
2. click **Configure Allowed IPs** and add the agent machine's address — a single
   IP is safer than a subnet. The default is `127.0.0.1` only;
3. restart the RPC server;
4. optionally tick **Auto-Start Server** so it comes up with FreeCAD.

### 2. On the agent machine

```bash
# CodeBuddy
codebuddy mcp add --scope user freecad -- uvx freecad-mcp --host <cad-host>
codebuddy mcp list          # expect: freecad ... ✓ Connected
```

`uvx` fetches and runs the published package; no clone is needed. For other MCP
clients the equivalent entry is:

```json
{
  "mcpServers": {
    "freecad": { "command": "uvx", "args": ["freecad-mcp", "--host", "<cad-host>"] }
  }
}
```

### 3. Verify before trusting

```bash
# is anything listening?
timeout 5 bash -c 'cat < /dev/null > /dev/tcp/<cad-host>/9875' && echo OPEN

# does the XML-RPC layer actually answer? (bypasses the MCP layer)
python3 -c "
import xmlrpc.client
print(xmlrpc.client.ServerProxy('http://<cad-host>:9875', allow_none=True).ping())"
```

If the first succeeds and the second reports *"Remote end closed connection
without response"*, the client IP is missing from the addon's allowlist — see
[lessons-learned A2](06-lessons-learned.md#a2-tcp-connects-but-every-xml-rpc-call-is-closed-with-no-response).

## How the work was actually done

The MCP surface used here is small: `execute_code`, `execute_code_async`,
`execute_code_headless`, `create_document`, `list_documents`, `get_rpc_status`,
`get_view`, `reload_document`. Nearly all real work went through
`execute_code` — writing FreeCAD Python directly is far more effective than
composing dozens of primitive tool calls.

A loop that worked well:

1. **Probe before building.** The first questions are always "what is actually
   available on this install?" — FreeCAD version, which workbenches and addons
   exist, which API surface is present. In this project the probe established
   that FCGear was *not* installed but `PartDesign.fcgear.involute` shipped with
   FreeCAD and could generate real involute profiles.
2. **Measure the convention, do not assume it.** The gear generator's tooth
   phase was established by measurement, twice, after the first measurement
   proved unreliable (see
   [lessons-learned C4](06-lessons-learned.md#c4-measure-gear-phase-at-the-pitch-circle-not-at-the-tip)).
3. **Build with parameters at module level** so later calls can reuse them — the
   `execute_code` namespace is persistent within a session.
4. **Verify numerically in the same breath as building.** Centre distance,
   interference volume, and the analytic volume of every cut.
5. **Keep screenshots off analytical steps** (`include_screenshot=False`) and
   take a view only when a visual is genuinely needed.

### Cost and latency habits

* Batch related geometry into one `execute_code` call; a round trip costs more
  than the extra statements.
* GUI operations run one at a time with a 90 s execution budget. Anything that
  may run for minutes (lofts, big booleans, FEM) belongs in
  `execute_code_async` with `commit()` for the document writes, or in
  `execute_code_headless`.
* `get_rpc_status` is answered off the GUI thread, so it is the tool to reach for
  when a call appears stuck.
* `execute_code_headless` runs **on the agent machine**, not the CAD machine —
  and its file paths are the agent machine's paths.

### Reproducing a remote model locally

The final models in `models/` were rebuilt from these scripts with a **local**
FreeCAD 1.0.0 (`freecadcmd`), while the originals were built on FreeCAD 1.1.0 on
the CAD machine. The verification suite passes on both; total volumes differ by
about 0.3 %, which is boolean-kernel drift between the two releases, not a
modelling difference.

| | remote build (1.1.0) | local rebuild (1.0.0) |
|---|---|---|
| single-stage total | 7747.4 cm³ | 7744.2 cm³ |
| two-stage total | 16352.6 cm³* | 16336.3 cm³ |

\* the two-stage figure shown is from the pre-fix build; see the note in
[verification](05-verification.md).

## Privacy note

The workflow uses a hostname and a LAN address, and the CAD host has a user
profile. Those are deliberately **not** recorded in this repository: placeholders
`<cad-host>` are used throughout, and the scripts contain no absolute paths or
credentials.

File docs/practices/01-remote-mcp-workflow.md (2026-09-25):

# The remote-MCP workflow

## Goal

Drive **FreeCAD running on a different machine** from an agent, over the
[Model Context Protocol](https://modelcontextprotocol.io), and produce real
engineering geometry rather than a toy demo.

```
┌─ agent machine ────────────────────────────┐   ┌─ CAD machine ────────────────┐
│                                            │   │                              │
│  CodeBuddy  ──stdio──▶  freecad-mcp        │   │   FreeCAD (GUI)              │
│  (LLM agent)            (MCP server,       │   │     └─ FreeCADMCP addon      │
│                          `uvx freecad-mcp  │──XML-RPC──▶  XML-RPC server     │
│                           --host HOST`)    │   │              :9875           │
│                                            │   │     (IP-allowlisted,         │
│                                            │   │      GUI-thread dispatch)    │
└────────────────────────────────────────────┘   └──────────────────────────────┘
```

Two components are involved and they are easy to confuse:

| component | runs on | role |
|---|---|---|
| `freecad-mcp` (Python package) | the **agent** machine | MCP server; translates MCP tool calls into XML-RPC |
| `FreeCADMCP` addon | the **CAD** machine, inside FreeCAD | XML-RPC server; executes code on FreeCAD's GUI thread |

## Setup

### 1. On the CAD machine

Copy `addon/FreeCADMCP` from the freecad-mcp repository into FreeCAD's addon
directory, restart FreeCAD, switch to the **MCP Addon** workbench, and in the
**FreeCAD MCP** toolbar:

1. tick **Remote Connections** (the server will bind `0.0.0.0` on next restart);
2. click **Configure Allowed IPs** and add the agent machine's address — a single
   IP is safer than a subnet. The default is `127.0.0.1` only;
3. restart the RPC server;
4. optionally tick **Auto-Start Server** so it comes up with FreeCAD.

### 2. On the agent machine

```bash
# CodeBuddy
codebuddy mcp add --scope user freecad -- uvx freecad-mcp --host <cad-host>
codebuddy mcp list          # expect: freecad ... ✓ Connected
```

`uvx` fetches and runs the published package; no clone is needed. For other MCP
clients the equivalent entry is:

```json
{
  "mcpServers": {
    "freecad": { "command": "uvx", "args": ["freecad-mcp", "--host", "<cad-host>"] }
  }
}
```

### 3. Verify before trusting

```bash
# is anything listening?
timeout 5 bash -c 'cat < /dev/null > /dev/tcp/<cad-host>/9875' && echo OPEN

# does the XML-RPC layer actually answer? (bypasses the MCP layer)
python3 -c "
import xmlrpc.client
print(xmlrpc.client.ServerProxy('http://<cad-host>:9875', allow_none=True).ping())"
```

If the first succeeds and the second reports *"Remote end closed connection
without response"*, the client IP is missing from the addon's allowlist — see
[A2](#a2-tcp-connects-but-every-xml-rpc-call-is-closed-with-no-response).

## How the work was actually done

The MCP surface used here is small: `execute_code`, `execute_code_async`,
`execute_code_headless`, `create_document`, `list_documents`, `get_rpc_status`,
`get_view`, `reload_document`. Nearly all real work went through
`execute_code` — writing FreeCAD Python directly is far more effective than
composing dozens of primitive tool calls.

A loop that worked well:

1. **Probe before building.** The first questions are always "what is actually
   available on this install?" — FreeCAD version, which workbenches and addons
   exist, which API surface is present. In this project the probe established
   that FCGear was *not* installed but `PartDesign.fcgear.involute` shipped with
   FreeCAD and could generate real involute profiles.
2. **Measure the convention, do not assume it.** The gear generator's tooth
   phase was established by measurement, twice, after the first measurement
   proved unreliable (see
   [design notes](../../../projects/reducers/docs/05-design-notes.md#establishing-the-generators-convention)).
3. **Build with parameters at module level** so later calls can reuse them — the
   `execute_code` namespace is persistent within a session.
4. **Verify numerically in the same breath as building.** Centre distance,
   interference volume, and the analytic volume of every cut.
5. **Keep screenshots off analytical steps** (`include_screenshot=False`) and
   take a view only when a visual is genuinely needed.

### Cost and latency habits

* Batch related geometry into one `execute_code` call; a round trip costs more
  than the extra statements.
* GUI operations run one at a time with a 90 s execution budget. Anything that
  may run for minutes (lofts, big booleans, FEM) belongs in
  `execute_code_async` with `commit()` for the document writes, or in
  `execute_code_headless`.
* `get_rpc_status` is answered off the GUI thread, so it is the tool to reach for
  when a call appears stuck.
* `execute_code_headless` runs **on the agent machine**, not the CAD machine —
  and its file paths are the agent machine's paths.

### Reproducing a remote model locally

The final models in `models/` were rebuilt from these scripts with a **local**
FreeCAD 1.0.0 (`freecadcmd`), while the originals were built on FreeCAD 1.1.0 on
the CAD machine. The verification suite passes on both; total volumes differ by
about 0.3 %, which is boolean-kernel drift between the two releases, not a
modelling difference.

| | remote build (1.1.0) | local rebuild (1.0.0) |
|---|---|---|
| single-stage total | 7747.4 cm³ | 7744.2 cm³ |
| two-stage total | 16352.6 cm³* | 16336.3 cm³ |

\* the two-stage figure shown is from the pre-fix build; see the note in
[verification](../../projects/reducers/docs/04-verification.md).

## Probe the remote environment every session — it is not stable

Two sessions driving the same addon recorded **contradictory** observations about
what `execute_code` provides. The difference matters, so it is recorded rather
than resolved:

| observation | session A | session B |
|---|---|---|
| `import Gui` | `ModuleNotFoundError` — no `PartDesign_*` GUI commands | not attempted |
| `App.Vector` | `AttributeError`; had to use `FreeCAD.Vector` | `App.Vector` used throughout |
| `obj.ViewObject` | accessible; colours could be set remotely | not attempted |
| script namespace across calls | **not** preserved | preserved (and the addon documents persistence) |

So: **probe at the start of each session** instead of trusting this table or the
documentation, and never let correctness depend on interpreter state surviving
between calls. If values must persist, write them to a module file and import it,
or attach results to document objects. That is what session A did, and it is the
robust choice regardless of which behaviour you get.

A related trap: `execute_code_headless` runs on the **agent** machine, not the CAD
machine (see [A3](#a3-execute_code_headless-does-not-run-on-the-remote-host)), so
"it worked last time" is not transferable between the two paths.

## Privacy note

The workflow uses a hostname and a LAN address, and the CAD host has a user
profile. Those are deliberately **not** recorded in this repository: placeholders
`<cad-host>` are used throughout, and the scripts contain no absolute paths or
credentials.

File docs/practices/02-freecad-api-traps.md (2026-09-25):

# FreeCAD API traps

Behaviour of FreeCAD's Python API that bites silently. Every entry was hit for
real; each is written *symptom → cause → fix → takeaway*.

These are properties of FreeCAD, not of any particular model, so they apply to
anything built with the `Part` API.

---

## 1. `Part::Feature.Shape` already has the Placement applied

**Symptom.** A feature cut in the object's local frame is simply not there. No
exception, no warning; the boolean "succeeds" and removes almost nothing.

**Cause.** Two facts combine badly:

1. Reading `obj.Shape` returns the shape **with `obj.Placement` already
   applied**. Measured: a local `Part.makeBox(10, 20, 30)` with a placement
   rotating Z→X and translating +100 in Y reports
   `Shape.Vertexes[0].Point == (30, 100, 0)` and
   `Shape.BoundBox == X[0,30] Y[100,110] Z[0,20]`.
2. Assigning `.Shape` and then `.Placement` makes FreeCAD **bake the rotation
   into the stored shape and reset the Placement to identity**. After
   `obj.Shape = local; obj.Placement = R`, `obj.Placement.Rotation.Q` is
   `(0, 0, 0, 1)` and the shape reads back already rotated.

So `gear.Shape = cut_local_feature(gear.Shape, ...)` cuts a local-frame tool into
an already-rotated shape. In the reducers here it cut two spurious slots into the
rim near `x ∈ [17.2, 21.3]` and produced **no hub keyway at all** — while the part
still passed `isValid()` and its volume changed only ≈0.1 %.

**Fix.** Do every local-frame feature operation on the solid **before** it is
assigned to a document object:

```python
solid = make_gear_solid(...)                 # local frame
solid = cut_hub_keyway(solid, ...)           # still local frame
obj.Shape = solid                            # assign once
obj.Placement = place
```

**Takeaway.** Never treat `obj.Shape` as "the thing I assigned". Either operate
on the intermediate solid, or accept that you are working in world coordinates.
And add a *positive* check that the feature exists where you expect it — a volume
delta and `isValid()` are not enough.

---

## 2. `App.Placement` translates **after** rotating, about the origin

**Symptom.** A cutter rotated onto a shaft's cross-section direction cuts
**0 mm³**. No error.

**Cause.** `p_world = R · p_local + t`, and `R` rotates about the **origin**, not
about the point you had in mind. Passing `t = axis` rotates the cutter all the
way around the world origin and lands it ~2·|axis| away.

**Fix.** To rotate about an axis through `axis`:

```python
t = axis - rot.multVec(axis)
tool.transformGeometry(App.Placement(t, rot).toMatrix())
```

**Takeaway.** Whenever a rotated cutter "does nothing", check the removal volume
against an analytic value — it is the fastest way to see that the boolean ran in
the wrong place.

---

## 3. Selecting a face by radius alone is ambiguous

**Symptom.** A coaxiality check reported a phantom 160 mm misalignment on a
design that is exact.

**Cause.** In that housing, `r = 62.5 mm` is *both* the 6214 bearing bore radius
*and* the 6209 boss outside radius. "The" cylindrical face of that radius was a
different shaft's.

**Fix.** Pass a positional hint and pick the nearest candidate:

```python
cylindrical_axis(shape, radius, near=expected_point)
```

---

## 4. `Shape.distToShape` returns 0 for touching *and* for overlapping

Two solids that merely touch have minimum distance 0 — and so do two solids that
overlap by a millimetre. A distance of 0 proves *contact*; it never proves
*absence of penetration*.

**Use intersection volume** (`a.common(b).Volume`) for interference, and keep
`distToShape` only for the separate claim "the surfaces actually meet".

---

## 5. Bounding boxes of boolean results are approximate

Measuring a centre distance from bound-box centres gave **159.888 mm** for a
design that is exactly 160.000 mm — a 0.11 mm error caused by discretised
geometry after fuse/cut.

Bounding boxes remain fine for *excluding* candidate pairs cheaply (see
[verification methodology](03-verification-methodology.md)). They are not good
enough to measure with. Read the true axis from a cylindrical face:

```python
for f in shape.Faces:
    s = f.Surface
    if s.TypeId == "Part::GeomCylinder" and abs(s.Radius - r) < 1e-6:
        return s.Center, s.Axis
```

---

## 6. `App.getDocument(name)` raises for an unknown name

```python
if App.getDocument("X"):        # NameError: Unknown document 'X'
```

It does **not** return `None`. Test membership instead:
`if "X" in App.listDocuments():`.

(The upstream freecad-mcp project hit the same trap and leaked raw XML-RPC faults
from it.)

---

## 7. A bearing can silently fuse into an invalid solid

**Symptom.** `shape.isValid()` returns `False` for an otherwise plausible
bearing, while the boolean reported success.

**Cause.** For a 6214 (70×125×24) with rings sized as 14 % of `(D − d)` and balls
at `0.95 ×` ring thickness, **`n_balls = 10` is invalid** while 9 and 11 are fine,
and 10 balls at `0.90` or `0.85` are also fine. The balls overlap both rings, and
with that particular spacing the fused intersection curves go bad.

**Fix.** Use 9 balls (which also matches the real 6214 ball diameter of ≈15 mm),
and assert validity. Alternatively skip the boolean entirely:
`Part.makeCompound([inner, outer, *balls])` is valid by construction and avoids
the failure mode — worth preferring when you do not need a single connected
solid.

**Takeaway.** After any fuse of tangent or overlapping solids, assert
`isValid()`. A boolean that returns a shape has not necessarily produced a good
one.

---

## 8. `ViewObject` is `None` under `freecadcmd`

Any line such as `obj.ViewObject.ShapeColor = ...` raises

```
AttributeError: 'NoneType' object has no attribute 'ShapeColor'
```

Keep colours, transparency and screenshots out of model builders; put them in a
separate GUI-only script. (`getattr(o, "ViewObject", None) is not None` is the
guard.)

---

## 9. A headless-saved document renders blank

**Symptom.** `saveImage()` succeeds and writes a PNG of exactly the requested
size — and the file is a uniform white rectangle.

**Cause.** `freecadcmd` has no view providers. A `.FCStd` written by a headless
build contains no `ViewObject` data, so when the GUI later opens it the objects
can come up with `Visibility` false.

**Fix.** Force visibility before rendering:

```python
for o in doc.Objects:
    vp = getattr(o, "ViewObject", None)
    if vp is not None:
        vp.Visibility = True
```

**Takeaway.** Sanity-check rendered output programmatically — a plausible file
size is not evidence of content. A blank 1600×1000 PNG compresses to about
7.7 kB; a real one is several times that.

---

## 10. `Part.Shape` has no `CenterOfMass`

```python
AttributeError: 'Part.Shape' object has no attribute 'CenterOfMass'
```

Use `shape.BoundBox.Center`, or `shape.Solids[0].CenterOfMass`.

---

## 11. `Shape.clean()` does not exist on a `Compound`

Boolean results are often `Part.Compound`, which has no `.clean()`. Use
`.removeSplitter()`.

---

## 12. Helper functions must encode the axis

A helper that builds along +Z — `cyl(r, z0, z1)` — called with `.translated()`
will not complain; it just silently produces a part pointing the wrong way. One
session's breather body ended up 50 mm clear of the housing this way, and a
`hex_prism(..., axis="Y")` fell through to the default branch because only `"X"`
was implemented, turning an oil-drain plug hex the wrong way.

**Fix.** Make the axis a required argument that raises on an unknown value, or
split the helpers by axis (`cyl_x` / `cyl_z`). Never let a silent default stand
in for a required decision.

---

## 13. `freecadcmd script.py` does not run the script

A positional argument to `freecad`/`freecadcmd` is a **document to open**, not a
script. Running `freecadcmd src/build_single_stage.py` prints the banner and
exits. Use:

```bash
freecadcmd -P src -c "import build_single_stage as m; m.main()"
```

`-P` puts `src/` on the Python path, so `__file__` is defined and the modules can
import each other.

For scripts that need a GUI, FreeCAD *does* execute a `.FCMacro` argument — which
is what the `render.sh` wrapper relies on.

---

## 14. Output redirected to a file is lost when a script raises

**Symptom.** `freecadcmd ... > log 2>&1` exits non-zero with a log containing
only FreeCAD's own banner — all `print()` output vanished, yet the same run looks
fine on a terminal.

**Cause.** FreeCAD's embedded interpreter exits through its C++ path, which does
not flush Python's `stdout` buffer. On a TTY, `print` is line-buffered and you
never notice.

**Fix.** `sys.stdout.reconfigure(line_buffering=True)` at the top of the script.

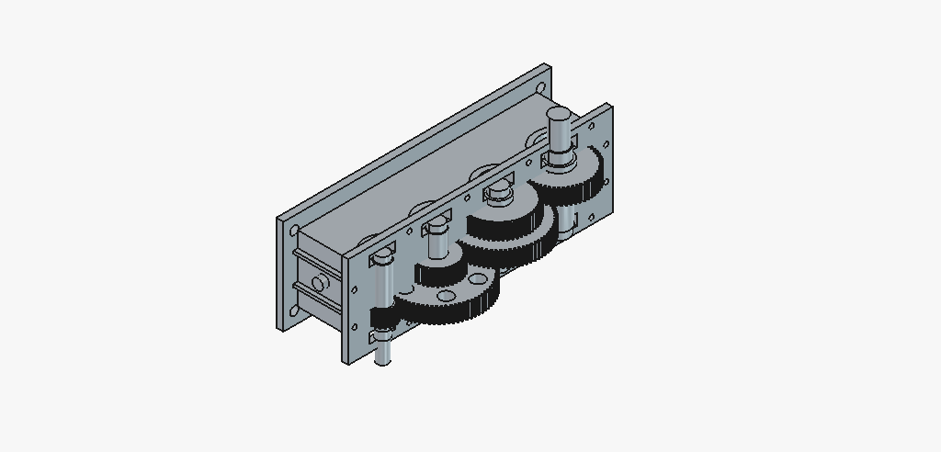
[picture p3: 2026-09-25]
projects/reducers/images/05-housing-base.png

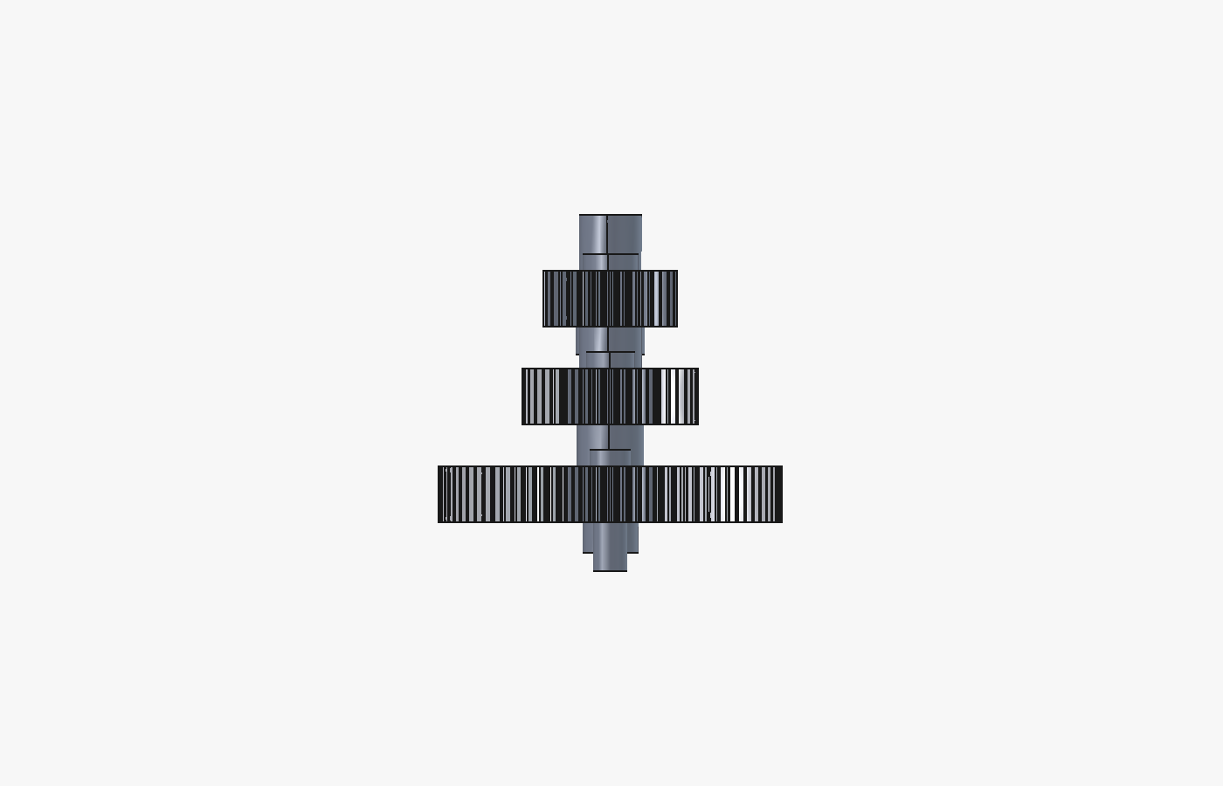
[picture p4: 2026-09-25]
projects/reducers/images/03-gear-train-v1-front.png

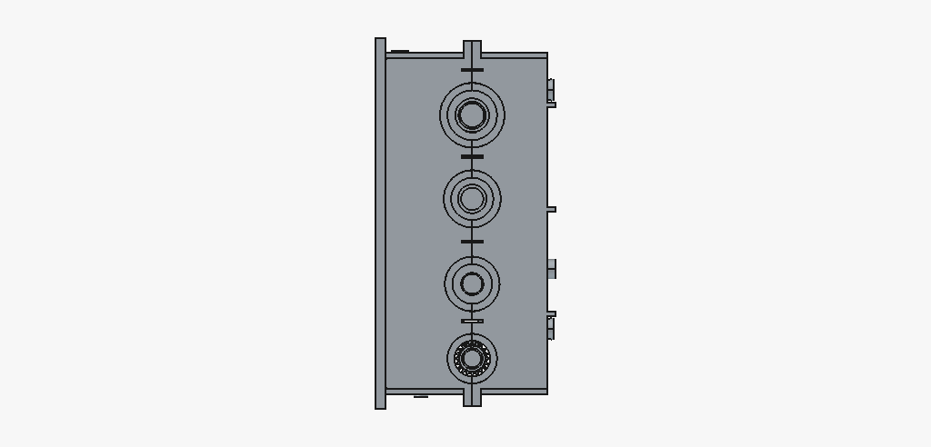
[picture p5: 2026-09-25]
projects/reducers/images/08-housing-bore-audit-top.png

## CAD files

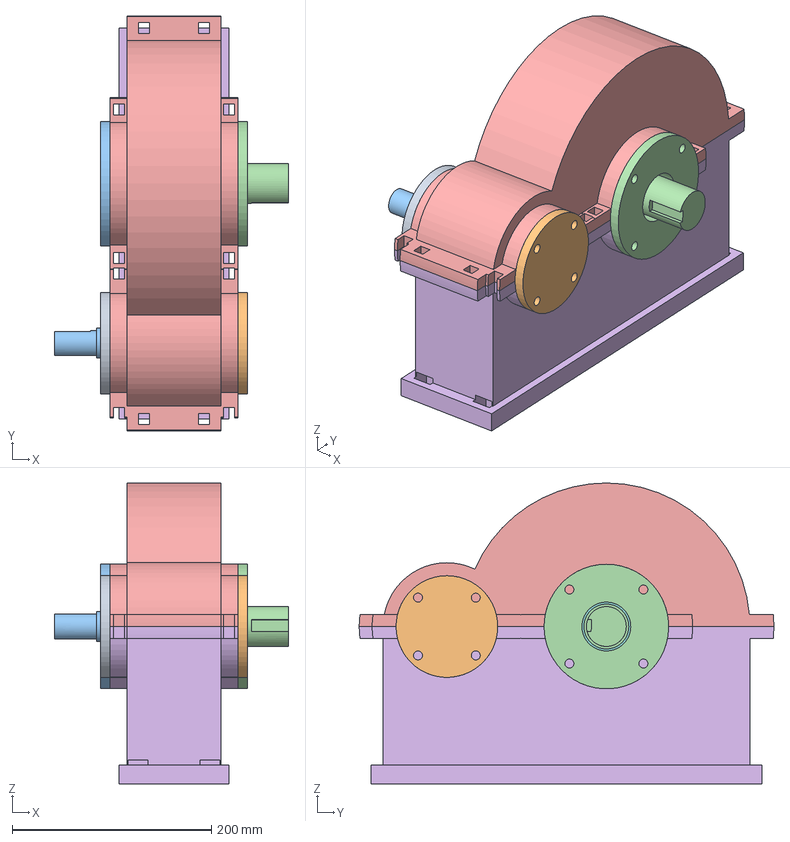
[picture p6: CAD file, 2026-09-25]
projects/reducers/models/original-build/Reducer.FCStd
235.0 x 416.0 x 302.0 mm
Pinion z=20
Gear z=60
Input shaft (HS)
Output shaft (LS)
Bearing 6206 (HS, left)
Bearing 6206 (HS, right)
Bearing 6209 (LS, left)
Bearing 6209 (LS, right)
End cap 6206 through (HS left)
End cap 6206 blind (HS right)
End cap 6209 blind (LS left)
End cap 6209 through (LS right)
Housing cover
Housing base

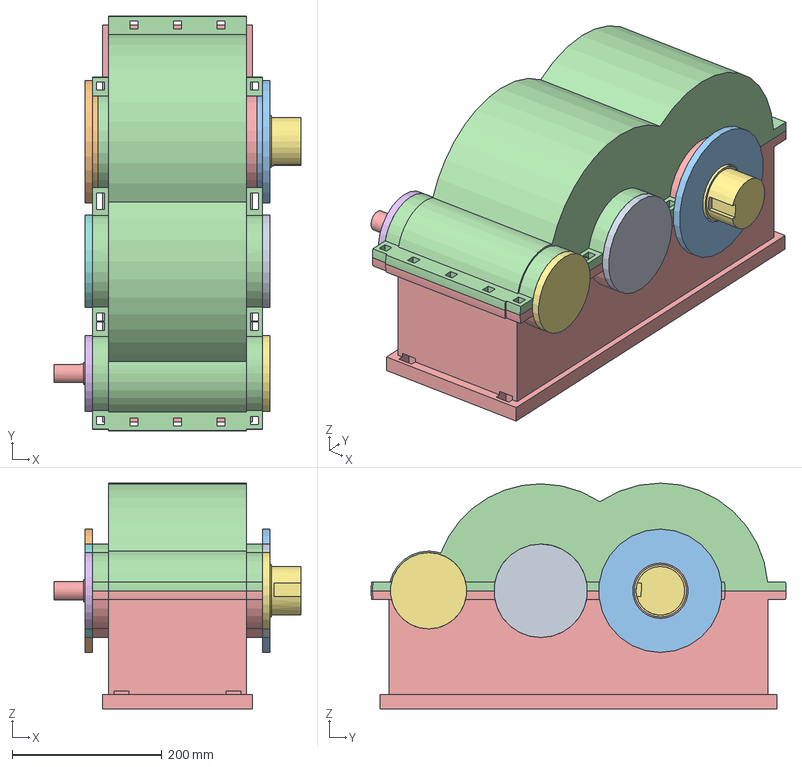
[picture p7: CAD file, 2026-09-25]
projects/reducers/models/reducer_two_stage.FCStd
330.0 x 555.0 x 302.0 mm
Stage-1 pinion z=20 (shaft I)
Stage-1 wheel z=80 (shaft II)
Stage-2 pinion z=20 (shaft II)
Stage-2 wheel z=60 (shaft III)
Shaft I (high speed, extends left)
Shaft II (intermediate, fully enclosed)
Shaft III (low speed, extends right)
Bearing 6206 (shaft I, left)
Bearing 6206 (shaft I, right)
Bearing 6209 (shaft II, left)
Bearing 6209 (shaft II, right)
Bearing 6214 (shaft III, left)
Bearing 6214 (shaft III, right)
End cap 6206 through (I left)
End cap 6206 blind (I right)
End cap 6209 blind (II left)
End cap 6209 blind (II right)
End cap 6214 blind (III left)
End cap 6214 through (III right)
Housing cover
Housing base

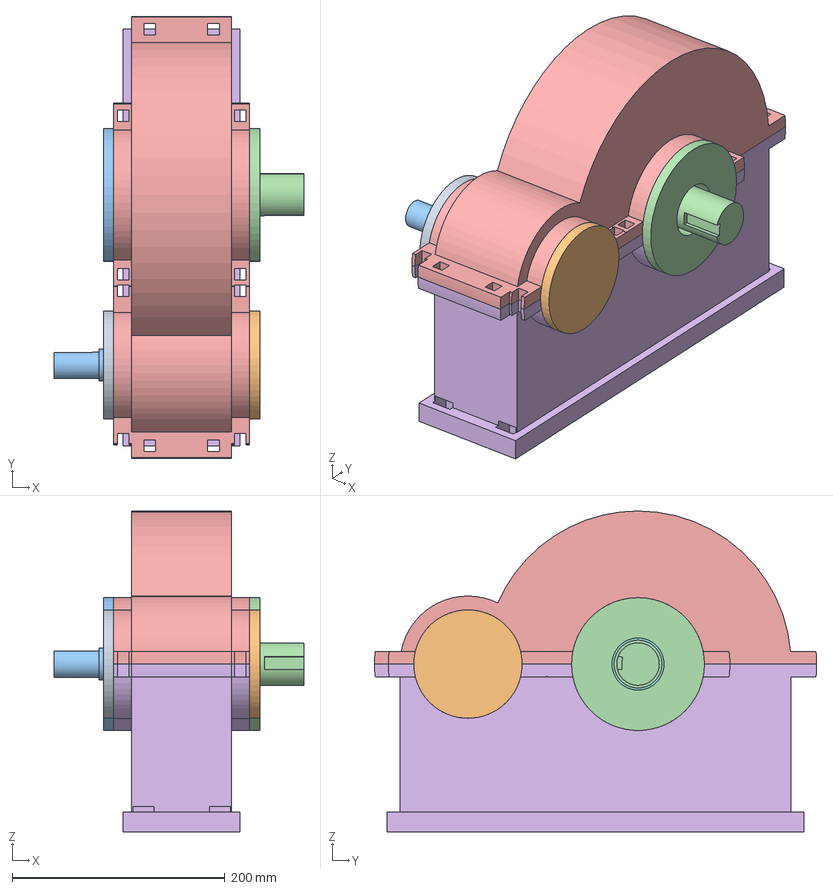
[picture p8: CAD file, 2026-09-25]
projects/reducers/models/reducer_single_stage.FCStd
235.0 x 416.0 x 302.0 mm
Pinion z=20
Gear z=60
Input shaft (HS)
Output shaft (LS)
Bearing 6206 (input, left)
Bearing 6206 (input, right)
Bearing 6209 (output, left)
Bearing 6209 (output, right)
End cap 6206 through (input)
End cap 6206 blind (input)
End cap 6209 blind (output)
End cap 6209 through (output)
Housing cover
Housing base

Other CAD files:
projects/reducers/models/original-build/Reducer_2stage.FCStd

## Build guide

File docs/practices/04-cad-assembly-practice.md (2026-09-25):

# CAD assembly practice

Lessons about *building assemblies* — mostly about split cast housings, where
almost every problem in this repository appeared. Written from the three-stage
build, which is where an assembly stops being a gear train and starts being a
machine.

---

## 1. Fuse every boss and flange **before** cutting the cavity

**Symptom.** The housing is solid and *every* transmission part reports
interference — ten parts at once.

**Cause.** A split-plane flange is a **solid plate**, not a ring. Cutting the
cavity first and fusing the flanges afterwards refills the cavity.

**Fix.** Fuse flanges, bearing bosses and ribs first; cut the cavity last.

**Takeaway.** When a boolean-fresh part suddenly collides with everything, check
the *order* of the boolean operations before suspecting a dimension.

---

## 2. Flanges must overhang, and the overhang must be relieved

Two coupled constraints on a split-plane flange:

* overhang only in ±Y and the flange bolts on the ±Z sides end up with their
  **nuts buried in the base casting** — 26905 mm³ of interference, at both ends;
* overhang in ±Z and the flange **blocks the shaft extensions**.

Resolution: overhang in every direction, then cut a relief at each bearing seat —
radius = boss radius + 8 mm, axial extent stopping **exactly** at the boss face
(going deeper starts removing the boss itself).

---

## 3. Ribs must clear the bolt-head circumscribed circle

A hex head's circumscribed radius is `across-flats / √3 ≈ 0.577·af`. Ribs that
look clear on centre lines will still clip a bolt head by tens to hundreds of
mm³.

These are the most expensive collisions to find, because the bounding boxes
overlap and the volume is tiny — no threshold on the volume will flag them, and
they do not show in a render. Check them deliberately.

---

## 4. Exactly coplanar contact faces produce numerical slivers

**Symptom.** A bolt head or nut face sitting *exactly* on the flange face reports
111 mm³ of interference. Nothing is actually wrong.

**Fix.** Inset the end face by 0.2 mm — invisible, and the sliver disappears.

**Takeaway.** Residual sub-mm³ "interference" between faces you deliberately
placed in contact is a numerics artefact, not a design error. Distinguish the two
by asking whether the parts are *meant* to touch.

---

## 5. Keep diameter steps out of the axial span of a through cap

A through end cap's central bore is sized on the diameter of the shaft that
passes through it. If the shaft steps up to a bigger diameter *inside* the cap's
axial span, the bore no longer clears the shaft.

Measured instance: the shaft went Ø45 → Ø40 at exactly the spigot face, and the
cap's Ø49 bore overlapped the Ø45 section by 26939 mm³. Fix: move the step outside
the cap span and extend the shaft.

---

## 6. A through cap's bore needs the min/max over all four end points

A flanged cap's geometry spans two features: the flange and the spigot. They have
four axial end points between them. Taking the min/max over only the two *inboard*
points leaves part of the flange undrilled, producing a large and otherwise
non-obvious shaft–cap collision.

---

## 7. Blind caps: the shaft end stops at the bearing outer face

Otherwise the shaft runs into the blind cap's spigot. Place every shaft end from
the bearing span: `x_end = wall inner face ± bearing width`.

---

## 8. The cavity floor must clear the lowest tooth of the whole train

This is the easiest way to quietly cut a wheel. A first attempt put the oil-sump
floor at `z = −120` while the largest wheel's teeth reached `z = −123.9`, removing
2578 mm³ from the gear.

Decide the floor from the largest tip radius in the train, plus the required
clearance, and leave ≥ 8–10 mm of casting below it.

---

## 9. Coordinate-system drift between sessions is a real risk

**Symptom.** Nothing *errors*, but every placement, phase formula, view direction
and cap/bearing axial definition is subtly wrong.

**Cause.** One session used **shafts along +Z with the housing split at X = 0**;
the repository's convention is **shafts along +X split at z = 0**. The gear-local
convention happened to match, which makes the divergence harder to spot.

**Fix / takeaway.** Write the conventions down at the top of the shared library
and read them before building, rather than working from memory of a previous
round. If a model from another session is to be merged, rotate it into the shared
frame — do not mix the two.

---

## 10. A threaded shank must be smaller than the tap drill

An M8 bolt modelled at its nominal Ø8 will not enter a Ø6.8 tap drill. Model
fasteners as two diameters: the shank that passes through the cap (Ø8) and the
threaded section that enters the housing (Ø6.6).

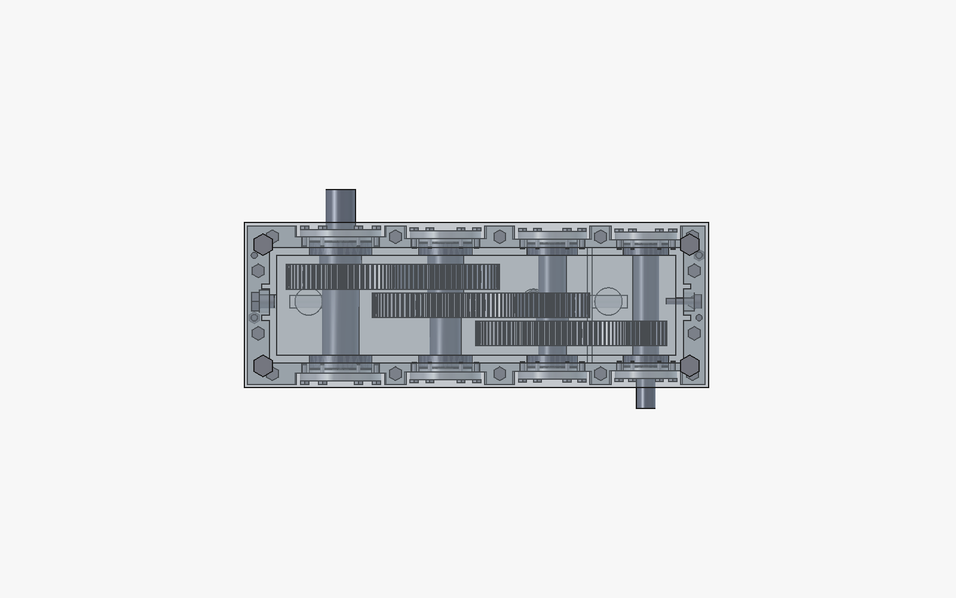
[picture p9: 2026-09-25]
projects/reducers/images/15-assembly-left.png

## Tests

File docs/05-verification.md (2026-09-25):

# Verification

`src/verify.py` re-opens a saved `.FCStd` and re-derives what it can from the
geometry itself, so the audit does not simply repeat the builder's assumptions.
Run it with:

```bash
freecadcmd -P src -c "import verify; verify.main('single')"   # single-stage
freecadcmd -P src -c "import verify; verify.main('two')"      # two-stage
```

It exits non-zero if any check fails. Both models pass with **zero failures**.

## What is checked, and why each check earns its place

| # | check | why it is not redundant |
|---|---|---|
| 1 | every solid is a valid BRep; every bearing passes `check_bearing` | a boolean can return a shape that `isValid()` rejects, and ball-count coincidences make this real (see [lessons E6/B6](06-lessons-learned.md#b6-a-bearing-can-silently-fuse-into-an-invalid-solid)) |
| 2 | gear tip radius, tooth count and face width match module and z | measuring the tip radius about the gear's **own axis** cross-checks `m·z` without counting teeth by eye; the tooth count is then counted independently by clustering the tip-circle vertices |
| 3 | each gear hub keyway is an actual void at the angle the mating shaft keyway uses | this is the check that catches the silent local-frame/world-frame mistake described in [lessons B1](06-lessons-learned.md#b1-partfeatureshape-already-has-the-placement-applied--and-this-one-is-silent) |
| 4 | shaft, bearing-bore and housing-bore axes are coaxial; centre distances exact | measured from cylindrical faces, not bounding boxes (bounding boxes are ~0.1 mm off after booleans) |
| 5 | no two parts share volume | the decisive test: `distToShape == 0` cannot distinguish "touching" from "overlapping" |
| 6 | each meshing pair touches **and** does not overlap | proves the phase alignment is right, not merely close |

## Design values asserted

| | single-stage | two-stage |
|---|---|---|
| centre distance | 160.000000 mm | 150.000000 / 160.000000 mm |
| gear tip radii | 44.004 / 124.001 mm | 33.003 / 123.000 / 44.004 / 124.001 mm |
| tooth counts | 20 / 60 | 20 / 80 / 20 / 60 |
| interference pairs | 91, all zero | 210, all zero |

Tolerance on every position check is 10⁻⁴ mm. Booleans are exact well below
that; the slack exists only so that a future kernel change does not produce
spurious failures.

## Output — single-stage

```
VERIFY models/reducer_single_stage.FCStd
objects: 14
-- 1. solid validity --          all PASS (bearings also pass integrity)
-- 2. gear geometry --
  [PASS] Gear_Pinion tip radius 44.004 (expect 44.000)   m=4.0
  [PASS] Gear_Pinion tooth count 20 (expect 20)
  [PASS] Gear_Pinion face width 50.00 (expect 50.0)
  [PASS] Gear_Wheel  tip radius 124.001 (expect 124.000) m=4.0
  [PASS] Gear_Wheel  tooth count 60 (expect 60)
  [PASS] Gear_Wheel  face width 45.00 (expect 45.0)
-- 3. gear hub keyways --
  [PASS] Gear_Pinion hub keyway present at (19.650, -0.000)
  [PASS] Gear_Wheel  hub keyway present at (-29.609, 1.552)
-- 4. axis alignment and centre distances --
  [PASS] Shaft_Input / Shaft_Output axes along X
  [PASS] centre distance Shaft_Input-Shaft_Output = 160.000000 (design 160.000)
  [PASS] 4 bearings coaxial with their shafts (offset 0.000000 mm)
  [PASS] housing bores coaxial with Shaft_Input / Shaft_Output
-- 5. pairwise interference --
  [PASS] no part pair intersects (91 pairs)
  [PASS] mesh Gear_Pinion-Gear_Wheel touches without overlap
ALL CHECKS PASSED
```

## Output — two-stage

```
VERIFY models/reducer_two_stage.FCStd
objects: 21
-- 1. solid validity --          all PASS (6 bearings also pass integrity)
-- 2. gear geometry --
  G1_Pinion_HS  r_tip  33.003 (33.000)  teeth 20 (20)  width 55.00
  G2_Wheel_HS   r_tip 123.000 (123.000) teeth 80 (80)  width 50.00
  G3_Pinion_LS  r_tip  44.004 (44.000)  teeth 20 (20)  width 65.00
  G4_Wheel_LS   r_tip 124.001 (124.000) teeth 60 (60)  width 60.00
-- 3. gear hub keyways --
  all four PASS at the direction their mating shaft keyway uses
-- 4. axis alignment and centre distances --
  [PASS] centre distance Shaft_HS-Shaft_MID  = 150.000000 (design 150.000)
  [PASS] centre distance Shaft_MID-Shaft_LS  = 160.000000 (design 160.000)
  [PASS] 6 bearings coaxial with their shafts (offset 0.000000 mm)
  [PASS] housing bores coaxial with Shaft_HS / Shaft_MID / Shaft_LS
-- 5. pairwise interference --
  [PASS] no part pair intersects (210 pairs)
  [PASS] mesh G1_Pinion_HS-G2_Wheel_HS touches without overlap
  [PASS] mesh G3_Pinion_LS-G4_Wheel_LS touches without overlap
ALL CHECKS PASSED
```

## Independent cross-checks

Two of the numbers are also verified by a completely different route, so a
systematic error in the builder would have to fool both:

* **Cut volumes.** Every keyway's boolean result is compared against the closed
  form for a rectangular slot in a cylinder
  ([lessons C6](06-lessons-learned.md#c6-cross-check-every-cut-against-an-exact-analytic-volume)).
  All twelve keyways across the two models agree to better than 0.1 %.
* **Housing clearances.** Oil-sump floor to lowest tooth = 6.0 mm,
  gear tip to cavity wall = 12.0 mm, both stated and re-measured.

## A note on the earlier builds

The first generation of these models — built on the CAD machine over MCP — had
**defective gear hub keyways**: cut in the local frame against an already-placed
shape, they removed no material from the bore and instead cut two spurious slots
into the rim near one face ([lessons B1](06-lessons-learned.md#b1-partfeatureshape-already-has-the-placement-applied--and-this-one-is-silent)).
The models committed here are rebuilt with the fix and fully audited; the
`Reducer.FCStd` / `Reducer_2stage.FCStd` files in `models/` are the originals for
comparison.

This is exactly why the build script and the audit script are separate programs.
The builder's own report said the keyways were fine.

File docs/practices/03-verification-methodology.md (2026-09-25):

# Verification methodology

How to convince yourself that generated CAD geometry is actually correct, rather
than merely plausible. Written from the mistakes that got through.

The governing rule: **the builder's report is not evidence.** A separate program
should re-open the saved file and re-derive what it can from the geometry itself.
That separation is what caught the defect described in
[API traps §1](02-freecad-api-traps.md#1-partfeatureshape-already-has-the-placement-applied)
— the builder had reported the keyways as fine.

---

## 1. Interference: intersection volume, nothing else

`Shape.distToShape` returns 0 both for touching and for overlapping solids. The
only sound test is the volume of the intersection:

```python
a.common(b).Volume        # > 0 means real interference
```

Keep `distToShape` for the *separate* claim "the surfaces actually meet", and use
them together to assert a correct mesh: distance ≈ 0 **and** volume == 0.

## 2. Pre-filter large pairwise sweeps with bounding boxes

41 parts is 820 pairs. A full sweep took **more than two minutes** and was
indistinguishable from a hang; the user thought FreeCAD had died. A bounding-box
overlap pre-filter cut it to 201 candidate pairs and finished in seconds with
identical conclusions.

```python
def overlap(a, b):                      # a, b: Shape.BoundBox
    return (a.XMin <= b.XMax and b.XMin <= a.XMax and
            a.YMin <= b.YMax and b.YMin <= a.YMax and
            a.ZMin <= b.ZMax and b.ZMin <= a.ZMax)

candidates = [(x, y) for x, y in itertools.combinations(objs, 2)
              if overlap(bb[x.Name], bb[y.Name])]
```

Bounding boxes are too crude to *measure* with, but entirely adequate to
*exclude* with.

## 3. Cross-check every cut against a closed-form volume

A rectangular slot of width `b` cut to depth `t1` into a cylinder of radius `R`
has cross-section

```
A = ∫(-b/2 .. b/2) ( sqrt(R² − y²) − (R − t1) ) dy
  = 2·( y/2·sqrt(R²−y²) + R²/2·asin(y/R) ) |₀^(b/2)  −  b·(R − t1)
```

Multiply by the length and the boolean must reproduce it to well under 0.1 %.
Every mismatch found this way had a real cause, and every cause was an *effective
length* subtlety rather than a formula error:

* a cutter deliberately overshooting the end of a shaft is clipped by the
  material, so the effective length is
  `min(x1, part_max) − max(x0, part_min)`;
* because the slot's corners are limited by the cylinder, the removed volume is
  slightly *less* than the naive `b · t1 · L` (2382.9 vs 2500 mm³ in one case) —
  which is correct, not a bug.

This one habit caught a misplaced coupling keyway (0 mm³ removed) and the missing
hub keyways, and confirmed every successful cut.

## 4. Measure axes from cylindrical faces, not bounding boxes

See [API traps §5](02-freecad-api-traps.md#5-bounding-boxes-of-boolean-results-are-approximate).
A correct 160.000 mm centre distance measured as 159.888 mm from bound-box
centres. Assert to 1e-6 mm from the underlying cylindrical surfaces.

## 5. Prove the check has discriminating power

Confirming "correct phase → 0 interference" is not enough. Rotate the driven gear
by half a tooth pitch and confirm you get ≈1900 mm³. Without that negative
control you cannot rule out a check that returns 0 for *any* input.

**A verification step that has never failed is an untested verification step.**
Seed each new check with a known-bad case at least once.

## 6. Assert that features exist, and let code produce the verdict

A hub-keyway check printed

```
empty inside hub keyway     ? True  (expect False)
```

which is a **failure** — `isInside` returning `True` means material is present,
i.e. no keyway. It was read as a pass because the line contained "True" and the
surrounding lines contained "PASS". The bug then survived a whole design cycle.

**Fix.** Make checks binary and machine-judged:

```python
def check(label, ok, detail=""):
    if not ok:
        FAILURES.append(label)
    print("  [%s] %-56s %s" % ("PASS" if ok else "FAIL", label, detail))
```

and exit non-zero. Never leave a raw value next to a hand-written expectation for
a human to interpret.

## 7. Measure gear tooth count independently

Clustering the vertices that lie on the tip circle recovers the tooth count
without counting teeth by eye, and cross-checks both the module and the phase.
Use half the expected pitch as the clustering threshold (the two vertices
bounding one tip arc are far closer together than adjacent teeth).

Watch the wrap-around: a cluster straddling the 0°/360° boundary counts as two,
which produced a phantom 21st tooth on a 20-tooth gear. Merge the wrap gap
explicitly:

```python
if (band[0] + 2 * math.pi) - band[-1] <= threshold:
    n -= 1
```

## 8. Find orphan parts with connectivity analysis

Build a graph of parts whose bounding boxes overlap, union-find the components,
and anything in a small component is floating. This caught a breather body
sitting **50.3 mm from the nearest part** — an error that reads as "a normal
boss" in a thumbnail.

## 9. Distinguish "still running" from "hung"

When a call appears stuck, check the RPC status — it is answered off the GUI
thread, so it works while a GUI operation is in flight:

* `state: busy` with `running_for_seconds` climbing → **it is running**; wait.
  `timeout_seconds = 0` means it will not time out on its own;
* `state: healthy` yet the call cannot get onto the GUI thread for 90 s →
  something else owns the GUI thread, and the usual culprit is a **modal dialog
  open on the remote FreeCAD**.

## 10. Check the assembly sequence, not just the final picture

Geometry that is correct in the assembled state can still be unbuildable. A
bearing slides on from a shaft end and is located by a shoulder, so going inwards
the diameter must be monotonically non-increasing until that shoulder. The same
logic decides which end a gear must be fitted from: one z = 60 wheel with a Ø60
bore could only go on from one end, because the other end had a Ø68 shoulder in
the way.

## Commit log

2026-09-25 Build three gear reducers by driving remote FreeCAD over MCP
    Two of the three designs are script-generated and committed with their
    models, plus an independent verification pass:
    single-stage i = 3.000, 2 shafts, 14 parts, a = 160
    two-stage i = 12.000, 3 shafts, 21 parts, a = 150 / 160
    three-stage i = 8.000, 4 shafts, 41 parts (documented, model not committed)
    src/ holds a reusable geometry library (involute gears via the built-in
    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
    [Reducer.FCStd, Reducer_2stage.FCStd, reducer_single_stage.FCStd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]
2026-09-25 Restructure as a practice repository, not a reducer repository
    The repository collects agentic FreeCAD working practice; the reducers are
    its first project rather than its subject. Two layers now:
    docs/practices/ design-agnostic knowledge
    projects/<name>/ self-contained builds
    The previous single lessons-learned document mixed the two, so it is split
    along that line:
    practices/02-freecad-api-traps.md silent API failures
    practices/03-verification-methodology.md proving geometry rather than trusting it
    practices/04-cad-assembly-practice.md boolean order, flanges, clearances
    practices/01-remote-mcp-workflow.md gains the session-environment caveat
    projects/redu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
    [Reducer.FCStd, Reducer_2stage.FCStd, reducer_single_stage.FCStd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]
